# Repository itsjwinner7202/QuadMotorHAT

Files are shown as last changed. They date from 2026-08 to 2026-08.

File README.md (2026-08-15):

# QuadMotorHAT

A simple Raspberry Pi HAT for controlling four DC motors.

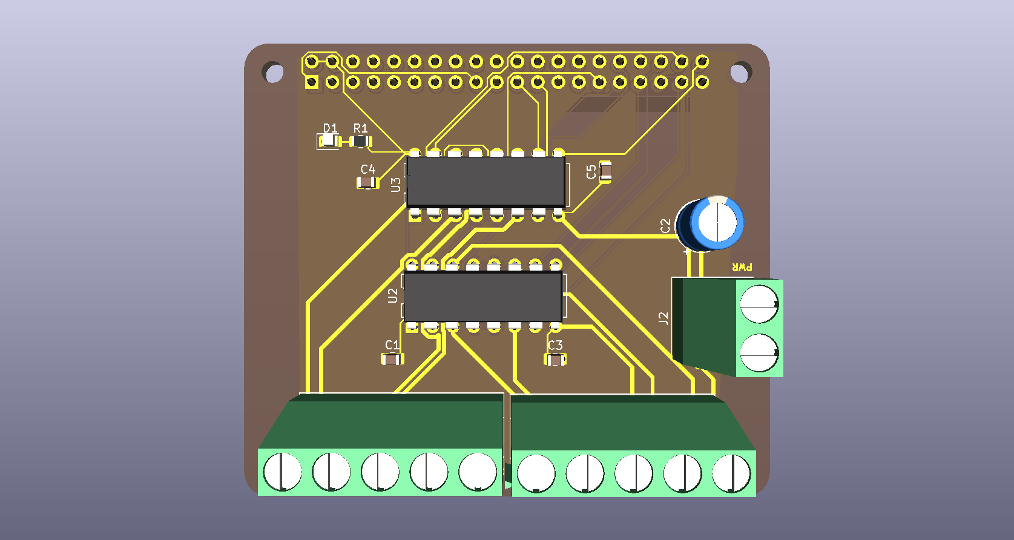
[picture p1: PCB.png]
QuadMotorHAT PCB


## Why I made it

While making my WRO robot, I ran into a problem: I needed to control multiple motors from a Raspberry Pi without a mess of separate boards and wiring.

There are already plenty of motor HATs available, but I wanted something simple that fit what I needed. So I decided to design my own.

## Features

* **4 motor control** — Control four motors from the Raspberry Pi using the included Python library.
* **Screw terminals** — Secure connections for the motors and power.
* **Compact design** — Keeps a low profile while leaving enough room for a cooling fan on the Raspberry Pi.
* **Simple Python control** — Control the motors directly from your Python project.

## Python Library

The repository includes `quadmotorhat.py`, which provides a simple interface for controlling the four motors.

First, install `gpiozero`:

```bash
pip install gpiozero
```

Then place `quadmotorhat.py` in the same directory as your Python program:

```text
your_project/
├── quadmotorhat.py
└── main.py
```

Import the motor controls:

```python
from quadmotorhat import M1, M2, M3, M4
```

You can then use `M1`, `M2`, `M3`, and `M4` to control the four motor outputs.

## PCB Files

The full board design is included in the repository.

* `QuadMotorHAT.kicad_sch` — Schematic
* `QuadMotorHAT.kicad_pcb` — PCB layout
* `QuadMotorHAT.kicad_pro` — KiCad project

You can open these files in KiCad to inspect or modify the design.

## License

This project is licensed under the terms of the license included in this repository.

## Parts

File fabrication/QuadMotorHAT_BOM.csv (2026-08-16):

Reference | Value | Datasheet | Footprint | Qty | DNP
C1,C3,C4,C5 | 0.1uF |  | Capacitor_SMD:C_0805_2012Metric | 4
C2 | 100uF 35V |  | Capacitor_THT:CP_Radial_D6.3mm_P2.50mm | 1
D1 | LED |  | LED_SMD:LED_0805_2012Metric | 1
J1 | GPIO |  | Connector_PinSocket_2.54mm:PinSocket_2x20_P2.54mm_Vertical | 1
J2 | MPWR |  | TerminalBlock_Phoenix:TerminalBlock_Phoenix_MKDS-1,5-2_1x02_P5.00mm_Horizontal | 1
J3 | M3/GND/M4 |  | TerminalBlock_Phoenix:TerminalBlock_Phoenix_MKDS-1,5-5_1x05_P5.00mm_Horizontal | 1
J4 | M1/GND/M2 |  | TerminalBlock_Phoenix:TerminalBlock_Phoenix_MKDS-1,5-5_1x05_P5.00mm_Horizontal | 1
R1 | 330 |  | Resistor_SMD:R_0805_2012Metric | 1
U2,U3 | L293D | http://www.ti.com/lit/ds/symlink/l293.pdf | Package_DIP:DIP-16_W7.62mm | 2

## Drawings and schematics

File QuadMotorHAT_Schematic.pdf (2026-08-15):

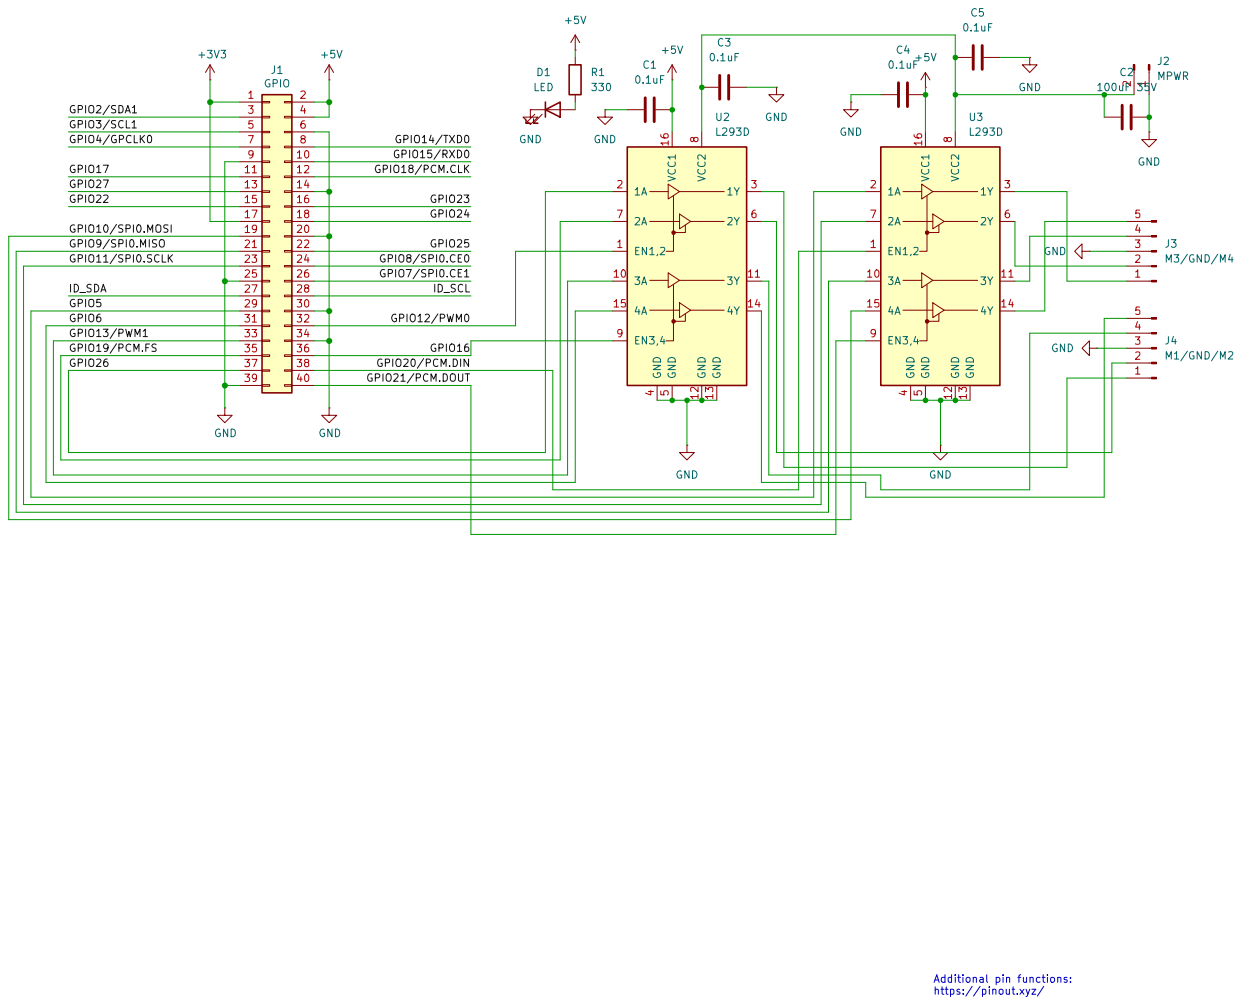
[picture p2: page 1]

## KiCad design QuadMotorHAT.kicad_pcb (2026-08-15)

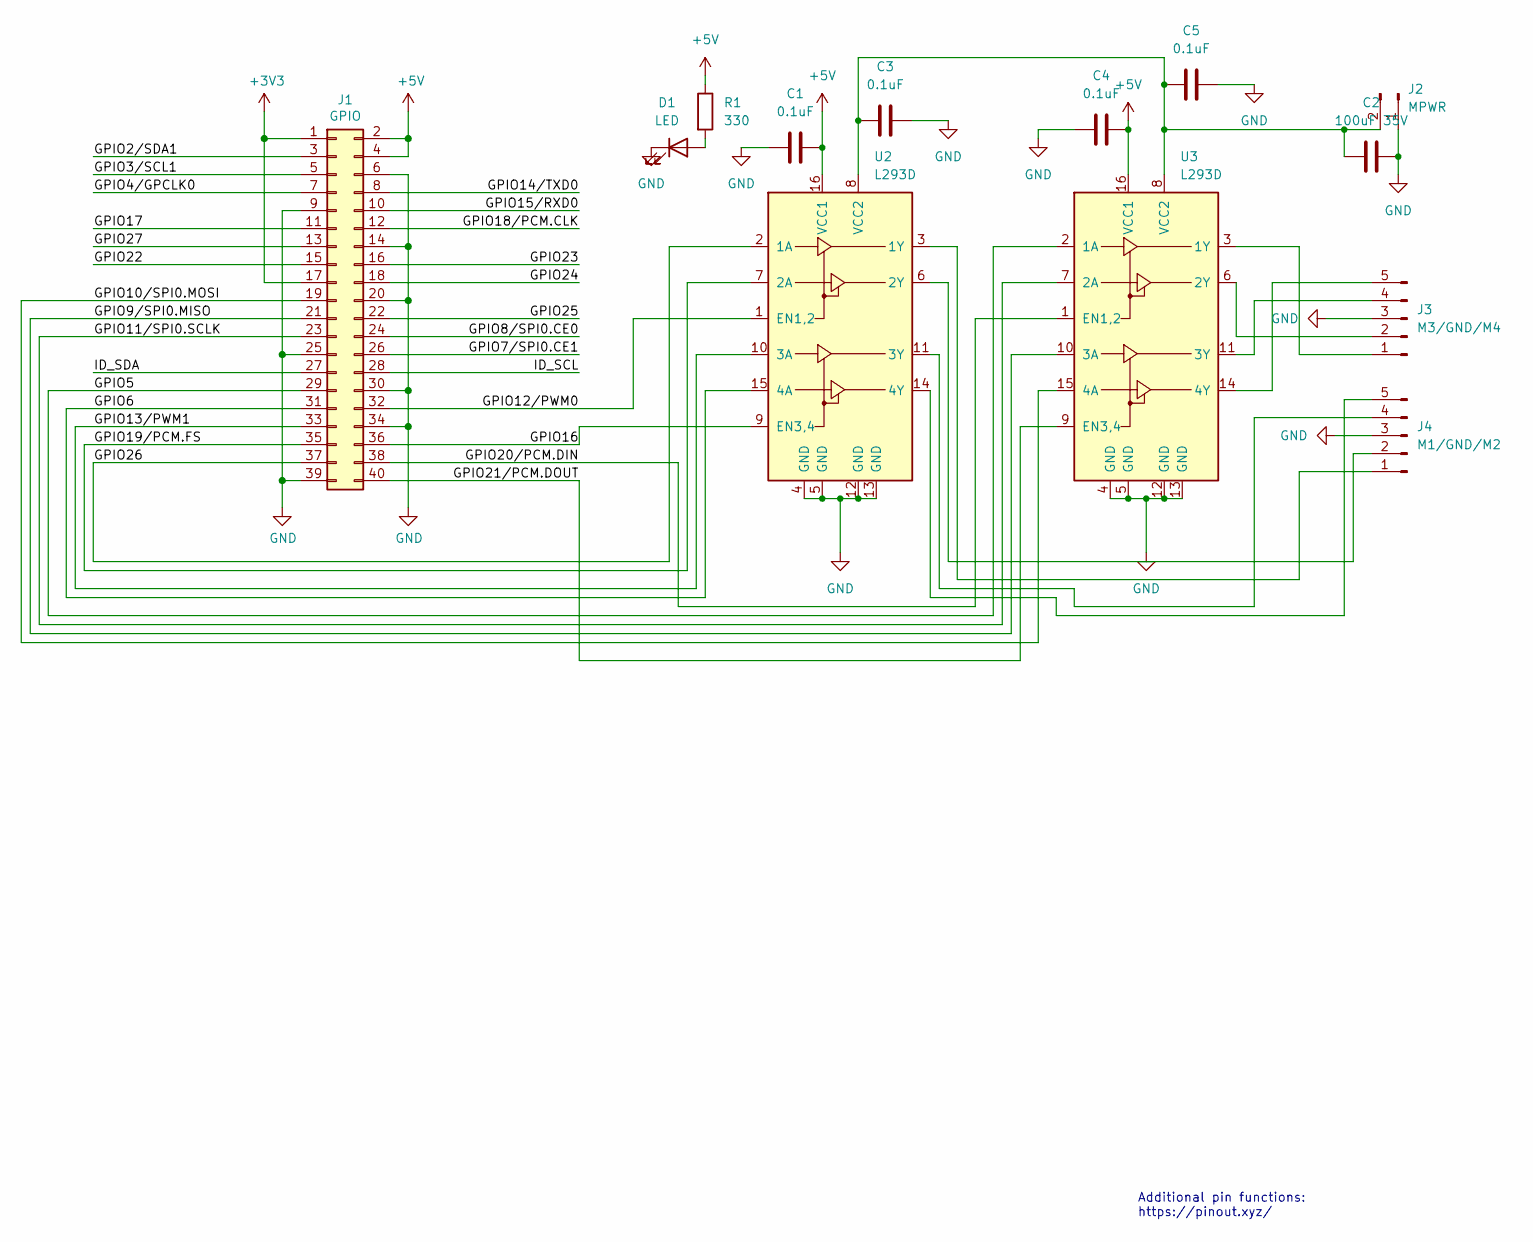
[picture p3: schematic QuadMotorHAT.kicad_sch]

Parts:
C1, C3, C4, C5: 0.1uF; C_0805_2012Metric
C2: 100uF 35V; CP_Radial_D6.3mm_P2.50mm
D1: LED; LED_0805_2012Metric
J1: GPIO; PinSocket_2x20_P2.54mm_Vertical
J2: MPWR; TerminalBlock_Phoenix_MKDS-1,5-2_1x02_P5.00mm_Horizontal
J3: M3/GND/M4; TerminalBlock_Phoenix_MKDS-1,5-5_1x05_P5.00mm_Horizontal
J4: M1/GND/M2; TerminalBlock_Phoenix_MKDS-1,5-5_1x05_P5.00mm_Horizontal
R1: 330; R_0805_2012Metric
U2, U3: L293D; DIP-16_W7.62mm

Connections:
+3V3: J1.1, J1.17
+5V: C1.2, C4.2, J1.2, J1.4, R1.1, U2.16 (VCC1), U3.16 (VCC1)
/GPIO2/SDA1: J1.3
/GPIO3/SCL1: J1.5
/GPIO4/GPCLK0: J1.7
/GPIO5: J1.29, U3.2 (1A)
/GPIO6: J1.31, U2.15 (4A)
/GPIO7/SPI0.CE1: J1.26
/GPIO8/SPI0.CE0: J1.24
/GPIO9/SPI0.MISO: J1.21, U3.10 (3A)
/GPIO10/SPI0.MOSI: J1.19, U3.15 (4A)
/GPIO11/SPI0.SCLK: J1.23, U3.7 (2A)
/GPIO12/PWM0: J1.32, U2.1 (EN1,2)
/GPIO13/PWM1: J1.33, U2.10 (3A)
/GPIO14/TXD0: J1.8
/GPIO15/RXD0: J1.10
/GPIO16: J1.36, U2.9 (EN3,4)
/GPIO17: J1.11
/GPIO18/PCM.CLK: J1.12
/GPIO19/PCM.FS: J1.35, U2.7 (2A)
/GPIO20/PCM.DIN: J1.38, U3.1 (EN1,2)
/GPIO21/PCM.DOUT: J1.40, U3.9 (EN3,4)
/GPIO22: J1.15
/GPIO23: J1.16
/GPIO24: J1.18
/GPIO25: J1.22
/GPIO26: J1.37, U2.2 (1A)
/GPIO27: J1.13
/ID_SCL: J1.28
/ID_SDA: J1.27
GND: C1.1, C2.2, C3.2, C4.1, C5.2, D1.1 (K), J1.6, J1.9, J1.14, J1.20, J1.25, J1.30, J1.34, J1.39, J2.1, J3.3, J4.3, U2.4 (GND), U2.5 (GND), U2.12 (GND), U2.13 (GND), U3.4 (GND), U3.5 (GND), U3.12 (GND), U3.13 (GND)
unnamed: D1.2 (A), R1.2
unnamed: C2.1, C3.1, C5.1, J2.2, U2.8 (VCC2), U3.8 (VCC2)
unnamed: J3.1, U3.3 (1Y)
unnamed: J3.2, U3.6 (2Y)
unnamed: J3.4, U3.11 (3Y)
unnamed: J3.5, U3.14 (4Y)
unnamed: J4.1, U2.3 (1Y)
unnamed: J4.2, U2.6 (2Y)
unnamed: J4.4, U2.11 (3Y)
unnamed: J4.5, U2.14 (4Y)

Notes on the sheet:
Additional pin functions: https://pinout.xyz/

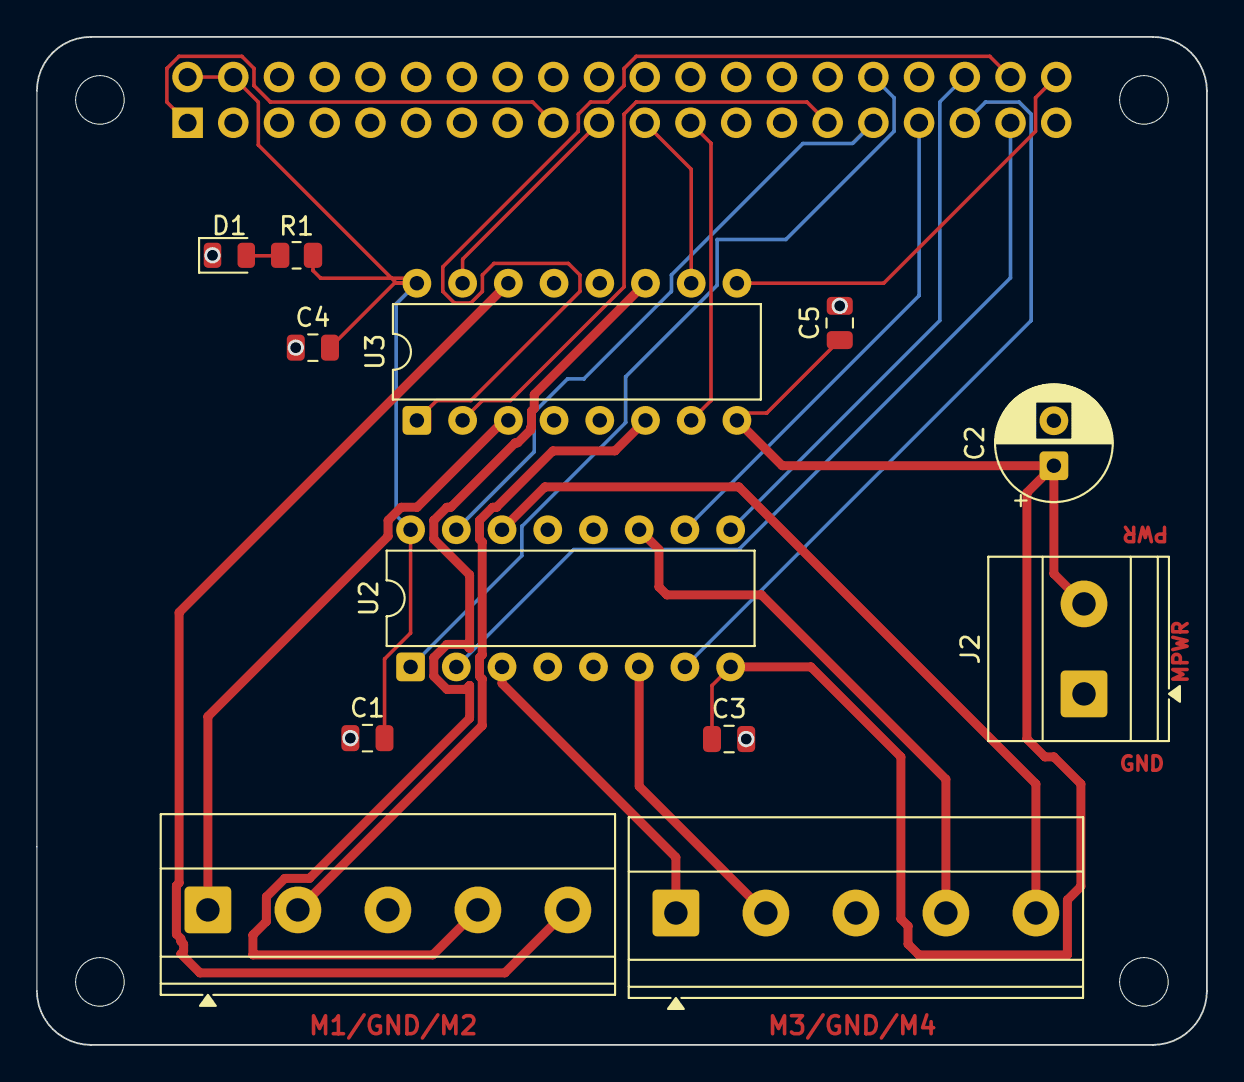
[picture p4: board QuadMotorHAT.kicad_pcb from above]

Board: 2 copper layers, 65.0 x 56.0 mm, 17 parts (1 on the bottom side), 25 nets.

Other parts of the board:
MH1, MH2, MH3, MH4: MountingHole_2.7mm_M2.5

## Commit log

2026-08-15 Improved PCB
    [QuadMotorHAT.kicad_pcb, QuadMotorHAT.kicad_sch]
2026-08-15 Improved PCB and added fabrication files
    [QuadMotorHAT.kicad_pcb, QuadMotorHAT_BOM.csv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]
2026-08-16 Fixed BOM and CPL
    [QuadMotorHAT_BOM.csv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]
